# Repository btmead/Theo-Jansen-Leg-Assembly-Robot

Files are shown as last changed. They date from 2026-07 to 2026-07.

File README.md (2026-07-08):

\# MENG2147 Walking Robot

https://github.com/user-attachments/assets/caa362a3-735c-47f6-9e61-454edf47af03

A SolidWorks, MATLAB, and Arduino-based walking robot project developed for MENG2147. The project combined mechanical linkage design, motion analysis, bill-of-materials planning, and embedded motor control.

\## Project Overview

This project designed and analysed a multi-leg walking mechanism driven through a crank/linkage system. The work included CAD modelling, kinematic simulation, leg displacement analysis, motor torque estimation, and Arduino-based RC motor control.

\## My Contributions

\- Designed and refined CAD components and assemblies in SolidWorks.

\- Analysed leg displacement and contact timing using MATLAB.

\- Produced motion visualisations and performance plots.

\- Implemented Arduino RC input mixing for differential motor control.

\- Prepared BOM and manufacturing drawings.

\- Assembled robot

\## System Architecture

\- CAD: SolidWorks parts, assemblies, and drawings.

\- Analysis: MATLAB processing of exported displacement data.

\- Firmware: Arduino RC pulse input, throttle/steering mixing, and PWM-style motor output.

\- Outputs: leg gait plots, motor torque plots, walking simulation media.

\## Mechanical Design

Four_Legs

Tasked with building a robot which used the Theo Jansen leg linkage we designed and created the legs and I created a crankshaft to be used which increased the strength of the mechanism

\## Motion Analysis

Two_legs_withTrace

The MATLAB script processes leg displacement data and identifies contact timing across the legs.

\## Firmware

The Arduino firmware reads two RC channels:

\- throttle

\- steering

It maps pulse widths from \\(1000\\ \\mu s\\) to \\(2000\\ \\mu s\\), applies a deadband around \\(1500\\ \\mu s\\), and outputs mixed left/right commands.

\## Repository Contents

| Folder | Contents |

|---|---|

| Media | Images and videos of mechanism motion |

| Firmware | Arduino motor control sketch |

| Analysis | MATLAB scripts and exported simulation data |

| Drawings | Selected manufacturing drawings |

| Documentation | BOM and project notes |

\## Tools Used

SolidWorks, MATLAB, Arduino, Excel.

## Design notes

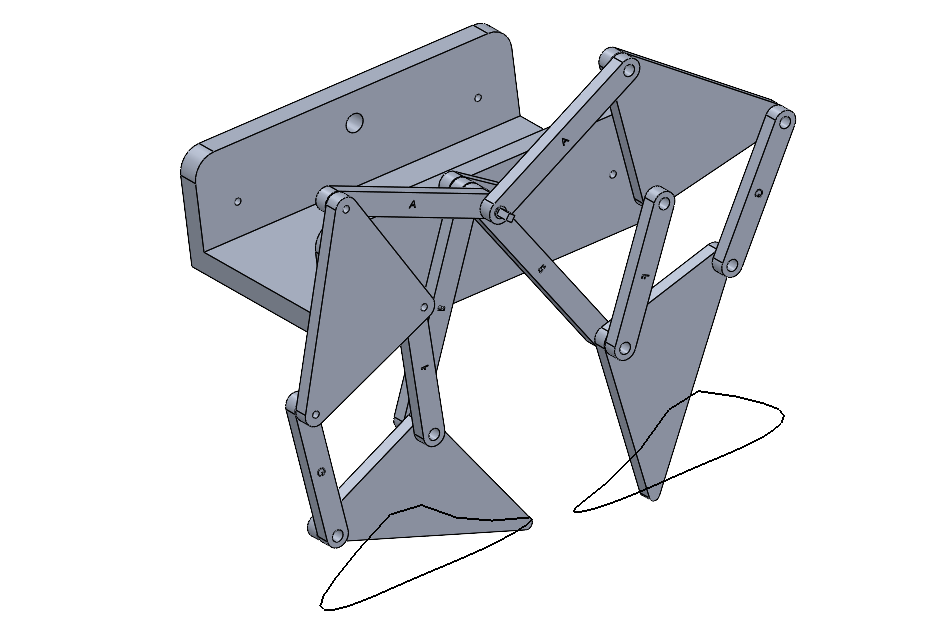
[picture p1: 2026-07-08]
Media/Two_legs_withTrace.png

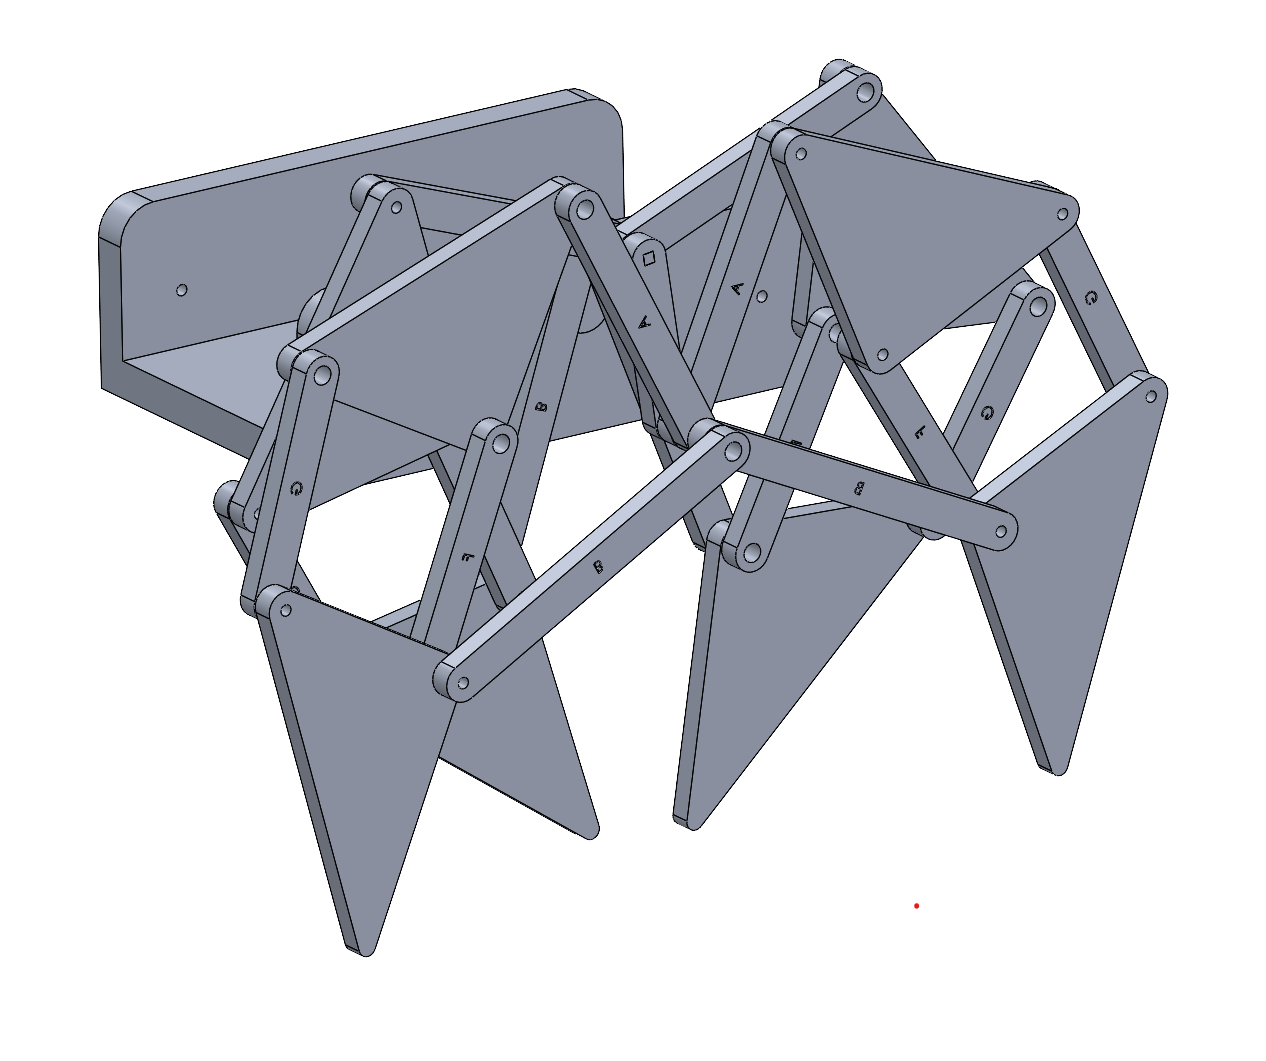
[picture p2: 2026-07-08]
Media/Four_Legs.png

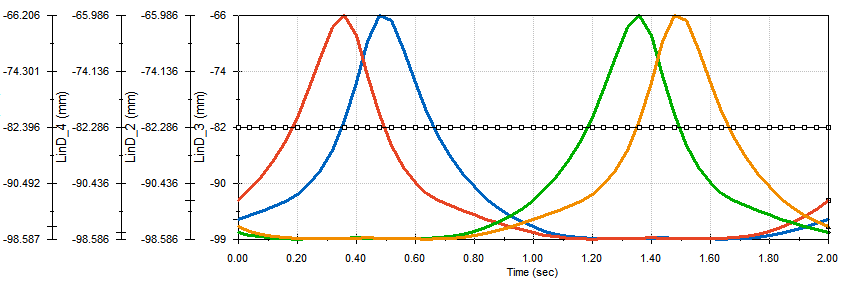
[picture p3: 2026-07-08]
Analysis/Linear_Displacement.png

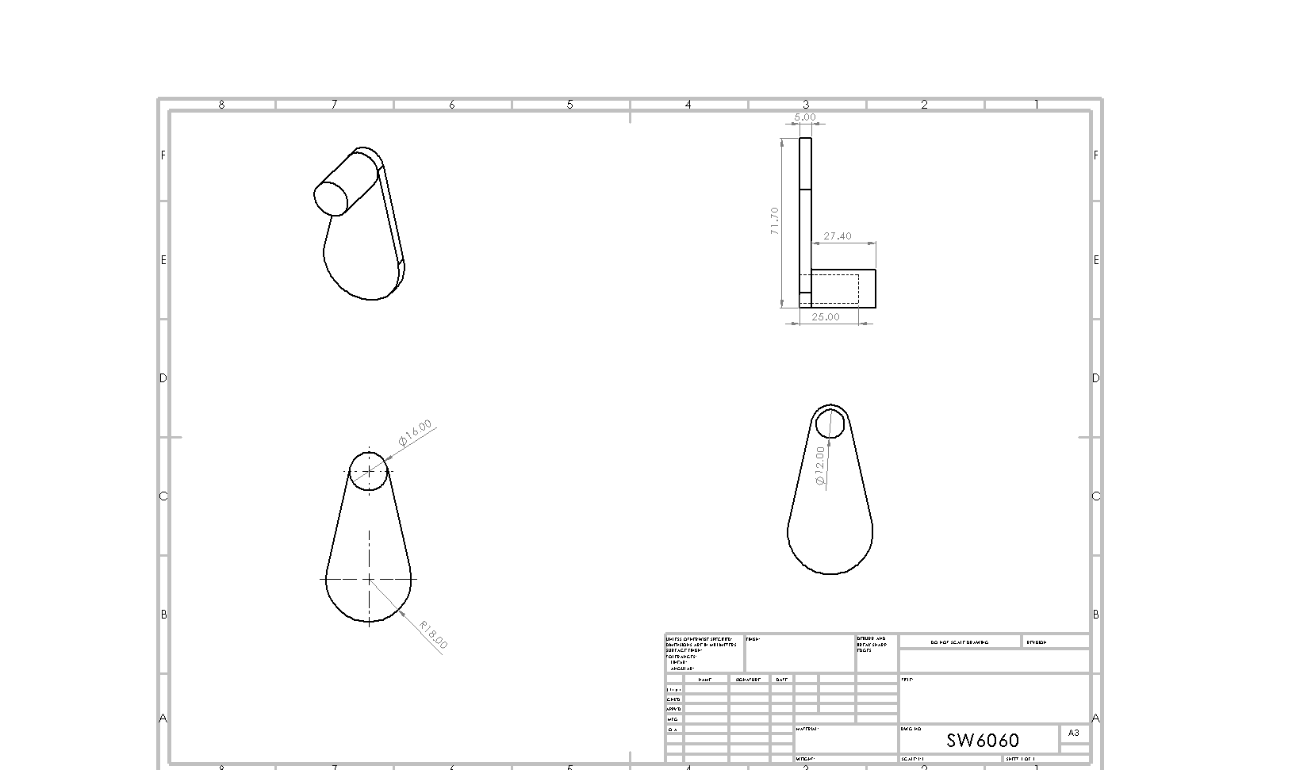
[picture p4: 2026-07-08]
Drawings/Crankshaft_B.PNG

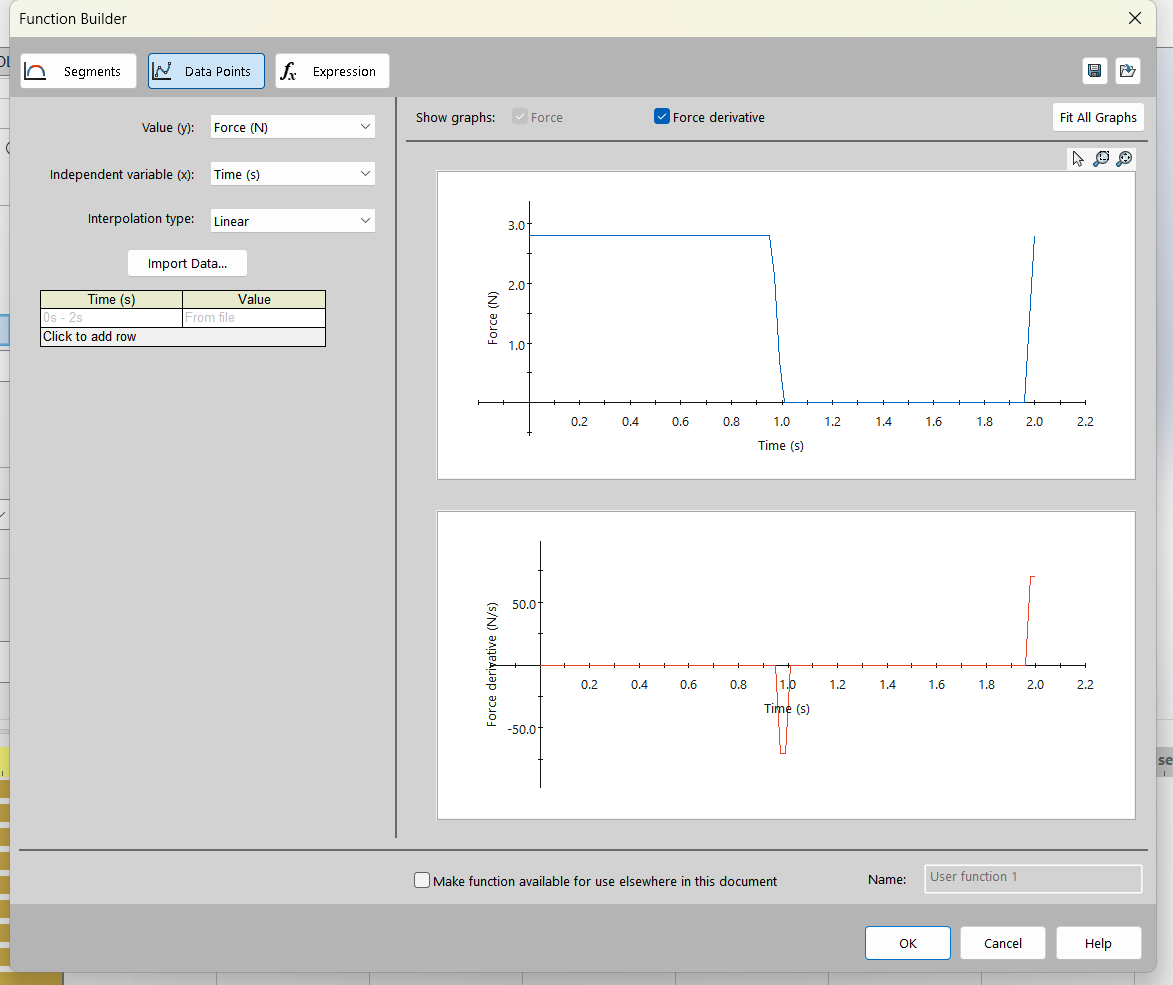
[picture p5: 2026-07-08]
Analysis/Force_Function.png

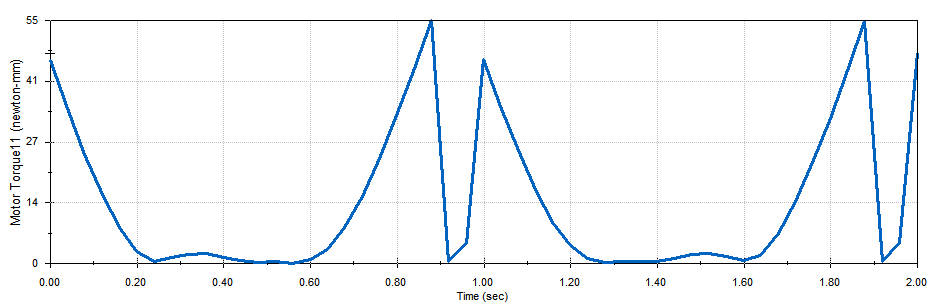
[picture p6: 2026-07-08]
Analysis/Motor_Torque.png

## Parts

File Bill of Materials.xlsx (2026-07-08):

Student Names |  | Clemi Scherzer, Ben Mead, Chloe DeJoy, James Wright |  |  | COURSE: | MENG 2417
Initiator / Team Input |  |  |  |  |  |  |  |  |  |  | Staff Input
REQUEST DATE | REQUESTOR | ITEM DESCRIPTION | PURPOSE | SUPPLIER / MANUFACTURER | SUPPLIER ITEM IDENTIFIER (PART NUMBER) | OTHER NOTES, SPECIFICATIONS, OR CONSTRAINTS | LINK | UNIT PRICE | QUANTITY | TOTAL COST | Ordered | Arrived | Notes
2026-03-25 | Clemi Scherzer | M3 locknut | misc. use on pivots and chassis | McMaster-Carr | 90576A102 |  | https://www.mcmaster.com/products/90576a102/ | $5.55 | 1 | $5.55
2026-03-25 | Clemi Scherzer | M4 washer | spacer | McMaster-Carr | 98269A430 |  | https://www.mcmaster.com/products/98269a430/ | $3.13 | 1 | $3.13
2026-03-25 | Clemi Scherzer | 4x20mm shoulder screw | 3-stack pivot | McMaster-Carr | 92981A145 |  | https://www.mcmaster.com/products/92981a145/ | $2.93 | 10 | $29.30
2026-03-25 | Clemi Scherzer | 4x15mm shoulder screw | 2-stack pivot | McMaster-Carr | 92981A743 |  | https://www.mcmaster.com/products/92981a743/ | $2.86 | 26 | $74.36
2026-03-25 | Clemi Scherzer | M2x8mm screw FH | crank shaft assembly | McMaster-Carr | 92125A054 |  | https://www.mcmaster.com/products/92125a054/ | $5.00 | 1 | $5.00
2026-03-25 | Clemi Scherzer | M3x8mm screw FH | crank shaft assembly | McMaster-Carr | 92125A128 |  | https://www.mcmaster.com/products/92125a128/ | $7.08 | 1 | $7.08
2026-03-25 | Clemi Scherzer | MOD 0.8 40T Pinion | drive pinion | GoBilda | 2300-4008-0040 |  | https://www.gobilda.com/2303-series-steel-mod-0-8-pinion-gear-8mm-rex-bore-40-tooth/ | $12.99 | 2 | $25.98
2026-03-25 | Clemi Scherzer | MOD 0.8 60T Gear | driven gear | GoBilda | 2302-0014-0060 |  | https://www.gobilda.com/2302-series-aluminum-mod-0-8-hub-mount-gear-14mm-bore-60-tooth/ | $11.39 | 2 | $22.78
2026-03-25 | Clemi Scherzer | Gear Hub | driven gear hub | GoBilda | 1309-0016-4008 |  | https://www.gobilda.com/1309-series-sonic-hub-8mm-rex-bore/ | $7.99 | 2 | $15.98
2026-03-25 | Clemi Scherzer | Larger Motor | larger drive motor | GoBilda | 5203-2402-0027 |  | https://www.gobilda.com/5203-series-yellow-jacket-planetary-gear-motor-26-9-1-ratio-24mm-length-8mm-rex-shaft-223-rpm-3-3-5v-encoder/ | $54.99 | 2 | $109.98
 |  |  |  |  |  |  |  |  |  | $0.00
 |  |  |  |  |  |  |  |  |  | $0.00
 |  |  |  |  |  |  |  |  |  | $0.00
 |  |  |  |  |  |  |  |  |  | $0.00
 |  |  |  |  |  |  |  |  |  | $0.00
 |  |  |  |  |  |  |  |  |  | $0.00
 |  |  |  |  |  |  |  |  |  | $0.00
 |  |  |  |  |  |  |  |  |  | $0.00
 |  |  |  |  |  |  |  |  |  | $0.00
 |  |  |  |  |  |  |  |  |  | $0.00
 |  |  |  |  |  |  |  |  |  | $0.00
 |  |  |  |  |  |  |  |  |  | $0.00
 |  |  |  |  |  |  |  |  |  | $0.00
 |  |  |  |  |  |  |  |  |  | $0.00
 |  |  |  |  |  |  |  |  |  | $0.00
 |  |  |  |  |  |  |  |  |  | $0.00
 |  |  |  |  |  |  |  |  |  | $0.00
 |  |  |  |  |  |  |  |  |  | $0.00
 |  |  |  |  |  |  |  |  |  | $0.00
 |  |  |  |  |  |  |  |  |  | $0.00
 |  |  |  |  |  |  |  |  |  | $0.00
 |  |  |  |  |  |  |  |  |  | $0.00
 |  |  |  |  |  |  |  |  |  | $0.00
 |  |  |  |  |  |  |  |  |  | $0.00
 |  |  |  |  |  |  |  |  |  | $0.00
 |  |  |  |  |  |  |  |  |  | $0.00
 |  |  |  |  |  |  |  |  |  | $0.00
 |  |  |  |  |  |  |  |  |  | $0.00
 |  |  |  |  |  |  |  |  |  | $0.00
 |  |  |  |  |  |  |  |  |  | $0.00
 |  |  |  |  |  |  |  |  |  | $0.00
 |  |  |  |  |  |  |  |  |  | $0.00
 |  |  |  |  |  |  |  |  |  | $0.00
 |  |  |  |  |  |  |  |  |  | $0.00
 |  |  |  |  |  |  |  |  |  | $0.00
 |  |  |  |  |  |  |  |  |  | $0.00
 |  |  |  |  |  |  |  |  |  | $0.00
 |  |  |  |  |  |  |  |  |  | $0.00
 |  |  |  |  |  |  |  |  |  | $0.00
 |  |  |  |  |  |  |  |  |  | $0.00
 |  |  |  |  |  |  |  |  |  | $0.00
 |  |  |  |  |  |  |  |  |  | $0.00
 |  |  |  |  |  |  |  |  |  | $0.00
 |  |  |  |  |  |  |  |  |  | $0.00
 |  |  |  |  |  |  |  |  |  | $0.00
 |  |  |  |  |  |  |  |  |  | $0.00
 |  |  |  |  |  |  |  |  |  | $0.00
 |  |  |  |  |  |  |  |  |  | $0.00
 |  |  |  |  |  |  |  |  |  | $0.00
 |  |  |  |  |  |  |  |  |  | $0.00
 |  |  |  |  |  |  |  |  |  | $0.00
 |  |  |  |  |  |  |  |  |  | $0.00
 |  |  |  |  |  |  |  |  |  | $0.00
 |  |  |  |  |  |  |  |  |  | $0.00
 |  |  |  |  |  |  |  |  |  | $0.00
 |  |  |  |  |  |  |  |  | TOTAL: | $299.14

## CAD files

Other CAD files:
Drawings/A_29.SLDDRW
Drawings/B_29.SLDDRW
Drawings/CDE_29.SLDDRW
Drawings/Crankshaft_B.SLDDRW
Drawings/F_29.SLDDRW
Drawings/G_29.SLDDRW
Drawings/HIJ_29.SLDDRW

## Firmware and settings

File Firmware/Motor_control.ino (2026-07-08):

#include <Servo.h>

const uint8_t RC_CHANNEL1_PIN = 2;
const uint8_t RC_CHANNEL2_PIN = 3;

const uint8_t LEFT_MOTOR_OUTPUT_PIN = 5;
const uint8_t RIGHT_MOTOR_OUTPUT_PIN = 6;

const int RC_MIN = 1000;
const int RC_MID = 1500;
const int RC_MAX = 2000;
const int RC_DEADBAND = 30;
const unsigned long RC_TIMEOUT = 25000;

Servo leftMotorOutput;
Servo rightMotorOutput;

int rcPulseToSignedCommand(uint8_t pin) {
  unsigned long pulseWidth = pulseIn(pin, HIGH, RC_TIMEOUT);

  if (pulseWidth == 0) {
    return 0;
  }

  pulseWidth = constrain(pulseWidth, RC_MIN, RC_MAX);

  if (abs((int)pulseWidth - RC_MID) < RC_DEADBAND) {
    return 0;
  }

  return map(pulseWidth, RC_MIN, RC_MAX, -500, 500);
}


void setup() {
  pinMode(RC_CHANNEL1_PIN, INPUT);
  pinMode(RC_CHANNEL2_PIN, INPUT);

  leftMotorOutput.attach(LEFT_MOTOR_OUTPUT_PIN);
  rightMotorOutput.attach(RIGHT_MOTOR_OUTPUT_PIN);

  leftMotorOutput.writeMicroseconds(RC_MID);
  rightMotorOutput.writeMicroseconds(RC_MID);
}

void loop() {
  int throttle = rcPulseToSignedCommand(RC_CHANNEL1_PIN);
  int steering = rcPulseToSignedCommand(RC_CHANNEL2_PIN);

  int leftMotor = throttle + steering;
  int rightMotor = throttle - steering;

  leftMotor = constrain(leftMotor, -500, 500);
  rightMotor = constrain(rightMotor, -500, 500);

  int leftCommand = leftMotor + 1500;
  int rightCommand = rightMotor + 1500;

  leftMotorOutput.writeMicroseconds(leftCommand);
  rightMotorOutput.writeMicroseconds(rightCommand);

  delay(20);
}

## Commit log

2026-07-08 Initial project commit
    [A_29.SLDDRW, B_29.SLDDRW, Bill of Materials.xlsx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]
2026-07-08 Added .gitignore and removed cachecad
    [action_log.csv, drive.csv, folder_dict.csv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]
